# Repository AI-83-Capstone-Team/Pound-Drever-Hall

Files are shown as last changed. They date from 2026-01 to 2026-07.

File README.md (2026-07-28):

# Pound-Drever-Hall Laser Locking System

A hardware/software co-design implementation of a **[Pound-Drever-Hall](https://en.wikipedia.org/wiki/Pound%E2%80%93Drever%E2%80%93Hall_technique) (PDH) laser frequency locking system** on a Red Pitaya STEMlab 125-14 (Xilinx Zynq XC7Z010 SoC). Real-time signal processing runs on the FPGA (PL), a TCP control server runs on the ARM cores (PS), and a Python client API provides remote operation from a host machine. This document covers the basics of the system and its operation.

---

## Table of Contents

0.  [Repository Structure](#repository-structure)
1.  [Why Would You Want This?](#why-would-you-want-this?)
2.  [PDH Conceptual Overview](#pdh-conceptual-overview)
3.  [System Overview](#system-overview)
4.  [Protocol Timing](#protocol-timing)
5.  [PID Controller](#pid-controller)
6.  [FIR Filter](#fir-filter)
7.  [Build and Deploy](#build-and-deploy)
8.  [Hardware Specifics](#hardware-specifics)

---

## Repository Structure

```
core/
  hw/
    prj/pdh_core/
      rtl/               FPGA RTL (SystemVerilog)
        pdh_top.sv       Board-level wrapper: clocking, PS instantiation, HP0 AXI tie-offs
        pdh_core.sv      Main control module: command decoder, IQ rotation, IQ demod, DMA orchestrator
        nco.sv           Numerically controlled oscillator (dual-output, quarter-ROM)
        iq_demod.sv      Instantaneous-product demodulator (configurable ref × input, Q15)
        pid_core.sv      Discrete PID with EMA derivative, anti-windup, decimation
        bram_controller.sv  Dual-clock BRAM capture buffer (pdh_clk write / fclk0 read)
        dma_controller.sv   AXI4 master for HP0 DDR burst writes
        sine_qtr_rom.sv  4096-entry, 16-bit quarter-sine ROM
        posedge_detector.sv  Rising-edge detector utility
      tb/                Testbenches (SystemVerilog, Icarus)
  sim/                   All RTL simulations (cocotb)
    run_regression.py      Runner for the command-echo regression test
    run_bode.py            Open-loop Bode analysis simulation
    run_fir_freq.py        FIR frequency-response verification simulation
    utils/
      test_pdh_core.py     cocotb test module — command-echo checks for every RTL register
      test_bode.py         cocotb test module — open-loop Bode measurement
      test_fir_freq_response.py  cocotb test module — FIR frequency response vs ideal
    Makefile.cocotb        cocotb regression make rules
    Makefile.bode          Bode sim make rules
    Makefile.fir_freq      FIR freq-response make rules
    artifacts/             Auto-indexed simulation output (JSON, CSV, PNG)
  sw/
    server.c            
    control/
      control.c          Command handler implementations
      hw_common.c        Hardware abstraction: mmap of AXI GP0 and HP0 DMA region; UIO interrupt primitives
      inc/
        server.h         cmd_ctx_t, cmd_entry_t, output_item_t definitions
        hw_common.h      pdh_cmd_t, pdh_callback_t, dma_frame_t packed unions; all enums
        control.h        Command handler declarations
  dts/
    pdh_irq.dts          Device Tree overlay — binds /dev/uio/pdh_uio to IRQ_F2P[1] (GIC SPI 62)
client/
  gui.py                 Interactive tkinter GUI — full hardware control without scripting
  pdh_api/
    api.py               Python API functions wrapping each TCP command
    types.py             Enums and result dataclasses mirroring the C/RTL types
    fir_design.py        Windowed-sinc FIR lowpass design (shared by GUI and sim tooling)
  test.py                Board-level regression test and visualization script
sim/
  pdh.m                  MATLAB PDH signal simulation
  power_terms.m          MATLAB power series analysis
pcb/                     PCB design files
```

---

## Why Would You Want This?

An ideal laser is a light source where the emitted field is perfectly coherent. In other words, if you sample the field at any two points in space or any two points in time, there's a deterministic phase relationship between them. This doesn't actually happen in practice. Various noise sources can introduce photons that are out of phase with the main field, and once those mix in, the aggregate phase of the beam starts doing something partially random. At that point the deterministic relationship breaks down and the beam is no longer coherent. This is a problem when the exact phase or frequency of the laser needs to be maintained. One example is gravitational wave detection, where the phase difference between two laser beams encodes spatial distortion from a passing wave. Another is optical communication using Phase-Shift Keying (PSK), where information is encoded in the relative phase of the carrier. And since frequency is just the first derivative of phase and wavelength follows from frequency, random phase noise also translates to wavelength jitter — which matters in applications like laser isotope separation, where the wavelength needs to sit on the absorption line of a specific isotope. There are a bunch of other examples but they won't be covered here.

| Good Laser | Bad Laser |
|:---:|:---:|
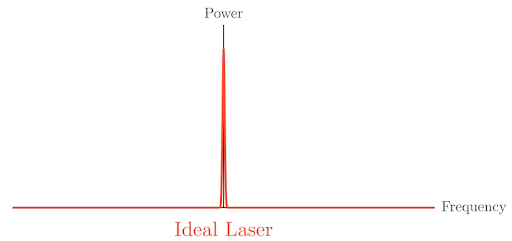
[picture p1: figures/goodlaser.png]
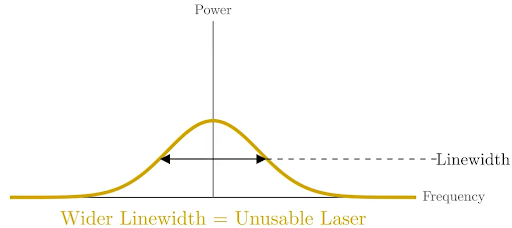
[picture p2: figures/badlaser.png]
|  |  |

#### TLDR; Really clean lasers can be useful.

---

## PDH Conceptual Overview

The main thing we can take advantage of is that if we keep the wavelength fixed, then by extension we can keep the phase fixed. We also know that we can adjust the wavelength by adjusting the amount of power we supply to the laser. We do this by using a frequency discriminator, which is a special optical component (generally either a Fabry Perot Cavity or a Ring Resonator) that emits a signal whenever the wavelength of the beam deviates from the resonance point. This is not good enough though because it doesn't tell us whether the wavelength is too wide or too narrow. To handle this, we use an Electro-Optic Modulator (EOM) to apply a periodic phase shift to the input beam. We then take the output beam and pass it to a photodiode to convert it to an electrical signal before multiplying it by the same sinusoidal signal driving our EOM. At this point, the multiplication product will reflect both the magnitude AND direction of our deviation from the resonance wavelength:

| Time Domain Representation | Frequency Domain Representation |
|:---:|:---:|
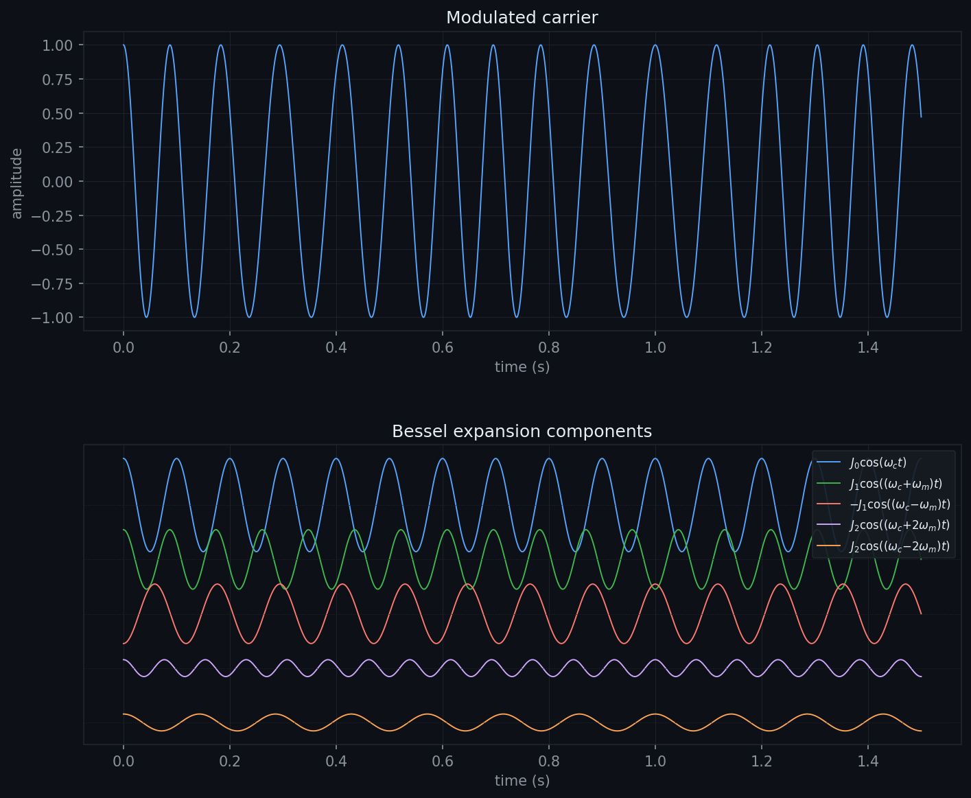
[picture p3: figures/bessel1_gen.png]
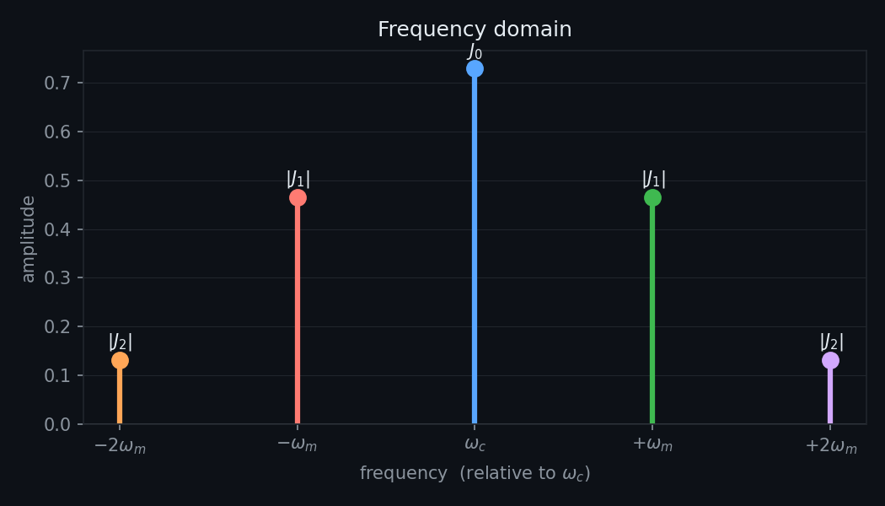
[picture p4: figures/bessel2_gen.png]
|  |  |

Above are time-domain and frequency domain representations of our modulated signal, which we can break into a series of superimposing sinusoids. The red and green tones are our sidebands, and we use them to encode the frequency offset information.

#### TLDR; Beam->EOM->Cavity->Photodiode->Demodulator
#### Alternative TLDR; We use the sidebands to encode our error signal, then demodulate them to extract it. From there we can generate a control signal to correct our laser.

---
## System Overview

The general idea behind the system is anything that needs to be done fast and/or deterministically and/or interact with the physical world is done on the FPGA, anything that doesnt but still needs to interact with the FPGA is done on the hard processor (ARM Cortex A9), and everything else is done client-side. The system is similar to [Linien](https://github.com/linien-org/linien), albeit much less polished and much more hackable. Hackability in this context refers to giving the user direct control over as much of the RTL as possible — you can basically wire the inputs and outputs of any two modules inside the system up to each other in any way that you wish, which makes rapid ad-hoc lab tests on the fly easy. As such, the system is not only useful as a laser spectroscopy lock, but also as a lightweight oscilloscope, spectrum analyzer, PID controller, FIR filter, and function generator all in one. 

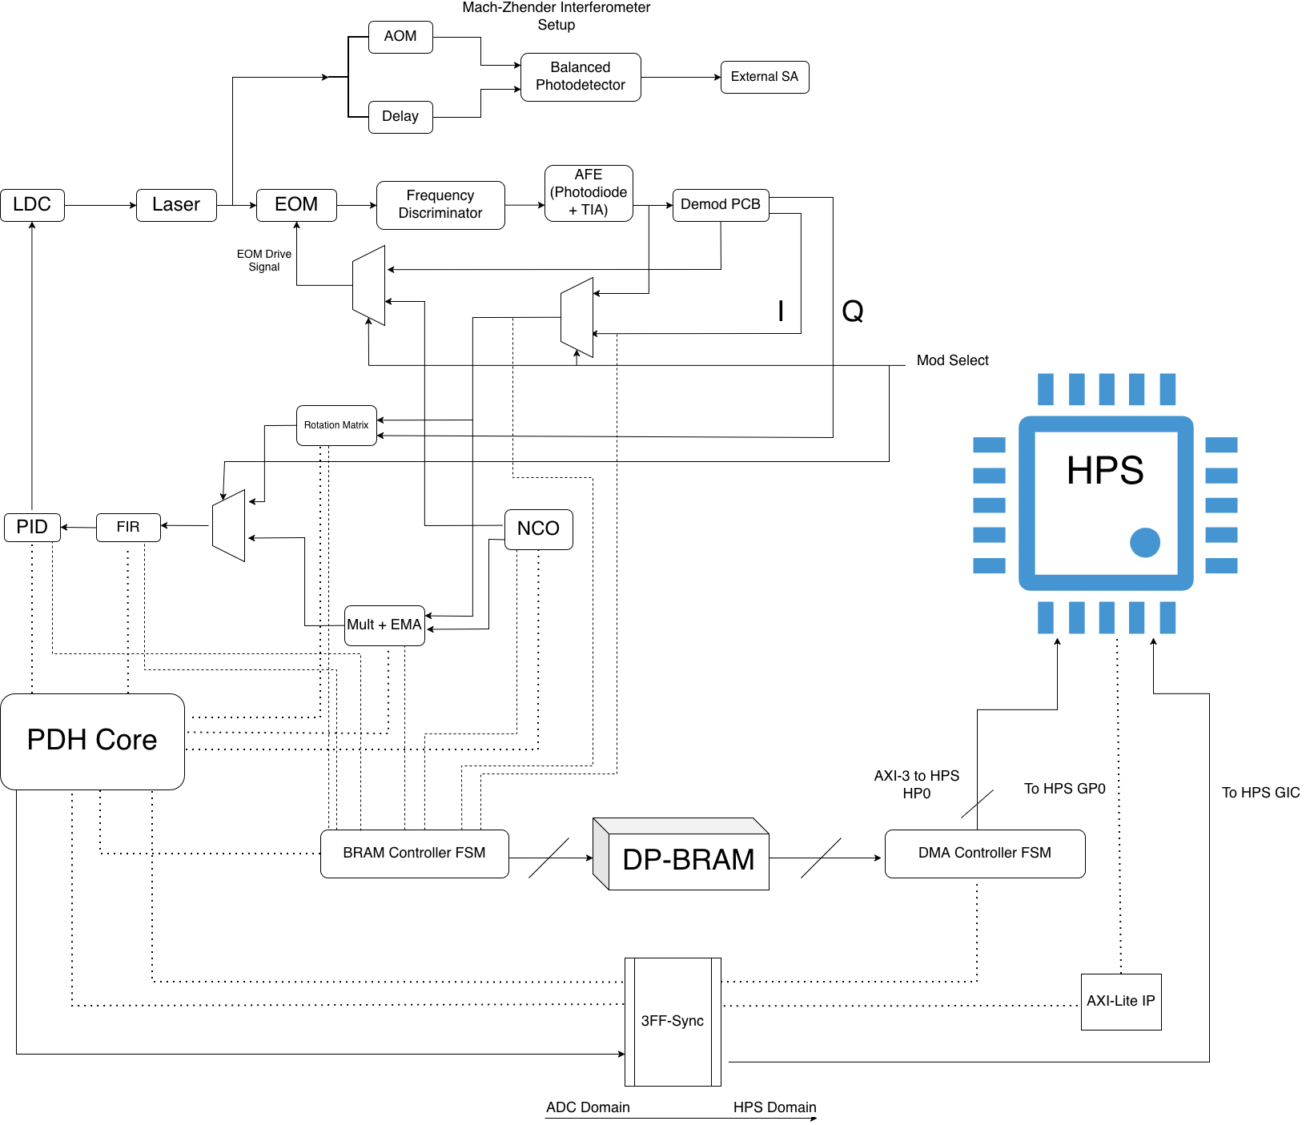
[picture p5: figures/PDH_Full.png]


In the diagram above, dotted lines indicate control/callback signals routed to/from submodules by the PDH core. Dashed lines indicate data taps that can be selected to feed the DMA engine. 

TLDR; it's a baby Moku.

---
## Protocol Timing

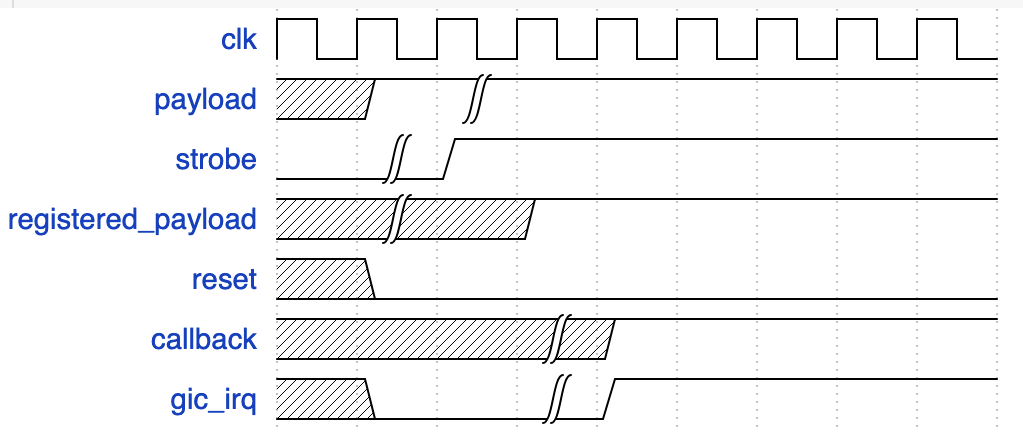
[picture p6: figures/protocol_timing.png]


The command word is 32 bits: [31]=reset, [30]=strobe, [29:26]=command code, [25:0]=payload. Every transaction consists of the PS writing the word twice, first with strobe low and then with strobe high. The FPGA passes the raw GPIO input through a 3-stage flip-flop synchronizer before decoding it, which handles the clock domain crossing between the PS AXI bus and the 125 MHz fabric clock. A posedge detector on the synchronized strobe fires when that edge comes through, latching the command word and executing it on that same clock cycle. The callback register is combinatorial off the current state, so it's valid at that same point. A 1-cycle GIC interrupt fires coincident with the strobe edge detection. The C server is blocked on a `read()` of `/dev/uio/pdh_uio`, which unblocks when the interrupt fires, and the callback register gets sampled.

`CMD_GET_FRAME` is different. No interrupt fires on the strobe. The DMA state machine runs through its sequence (BRAM fill at the decimated rate, then an AXI4 burst to DDR over HP0), and the interrupt fires when the transfer is done. The server side waits on `select()` with a timeout computed from the decimation depth rather than blocking indefinitely.

`CMD_IDLE` generates no interrupt at all. It just resets the DMA state machine back to armed so the next `CMD_GET_FRAME` starts clean.

The reset bit is completely separate from the strobe path and goes straight to the synchronous reset chain regardless of anything else in the word.

#### TLDR; PS writes command word twice (strobe 0→1), FPGA latches on the synchronized rising edge, callback is valid on that same clock cycle, interrupt tells the PS it's ready.

---
## PID Controller

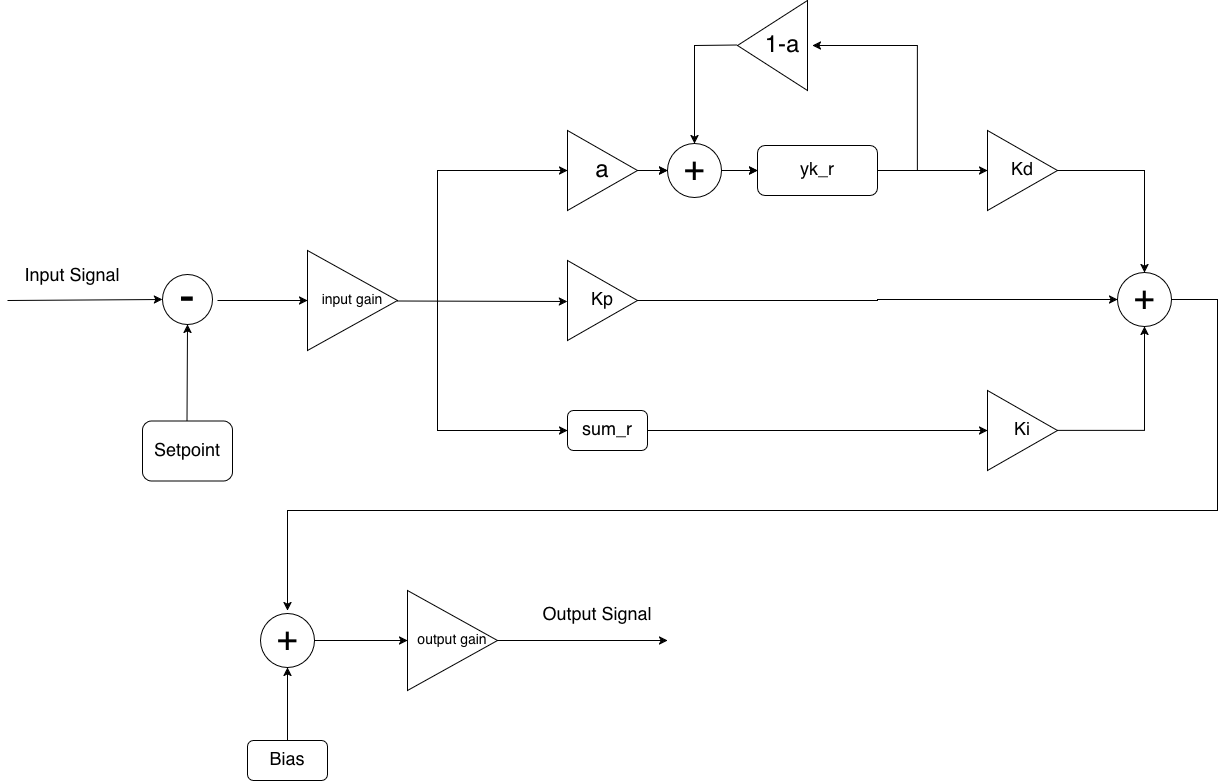
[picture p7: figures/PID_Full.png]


The block diagram shows the structure. The input signal has the setpoint subtracted, passes through the input gain stage (`egain`), and then splits into three paths: Kp directly, Kd via the EMA block, and Ki through the running integrator (`sum_r`). The three products are summed and then scaled by the output gain before the bias is added.

The derivative path is worth explaining since it's not a standard differentiator. The core keeps a running exponential moving average of the error (`yk_r` in the diagram). The alpha and (1-alpha) scaling blocks feed into that register's update loop, and Kd multiplies the difference between the current error and `yk_r`. That difference is the deviation of the error from its recent mean, which is a reasonable approximation of the derivative without being as noise-sensitive as a true differentiator. The alpha parameter sets the EMA time constant.

The integrator has saturation at ±2^`satwidth` and freezes in whichever direction would push it further when the output is already railed. Standard anti-windup. Without it the integrator winds up to full scale any time the system is outside the lock pull-in range and then takes forever to recover once it gets back in.

The output is 14-bit unsigned offset-binary (DAC code), with 0 V mapped to code 8191. The decimation parameter slows the PID update rate independently of everything else — the NCO, ADC, and DMA all still run at full rate, the PID output just holds between updates.

#### TLDR; Standard PID with EMA derivative and integrator anti-windup. Kp/Ki/Kd are Q15 fractions, input and output gain stages let you scale without touching the individual terms.

---
## FIR Filter

| Original Signal | Sampling at Decimated Rate |
|:---:|:---:|
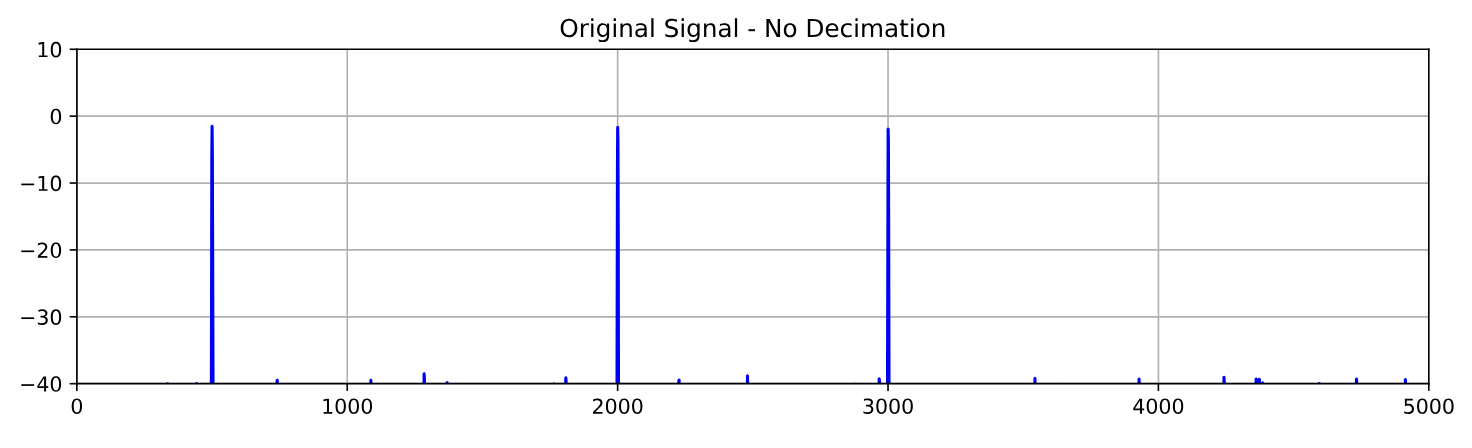
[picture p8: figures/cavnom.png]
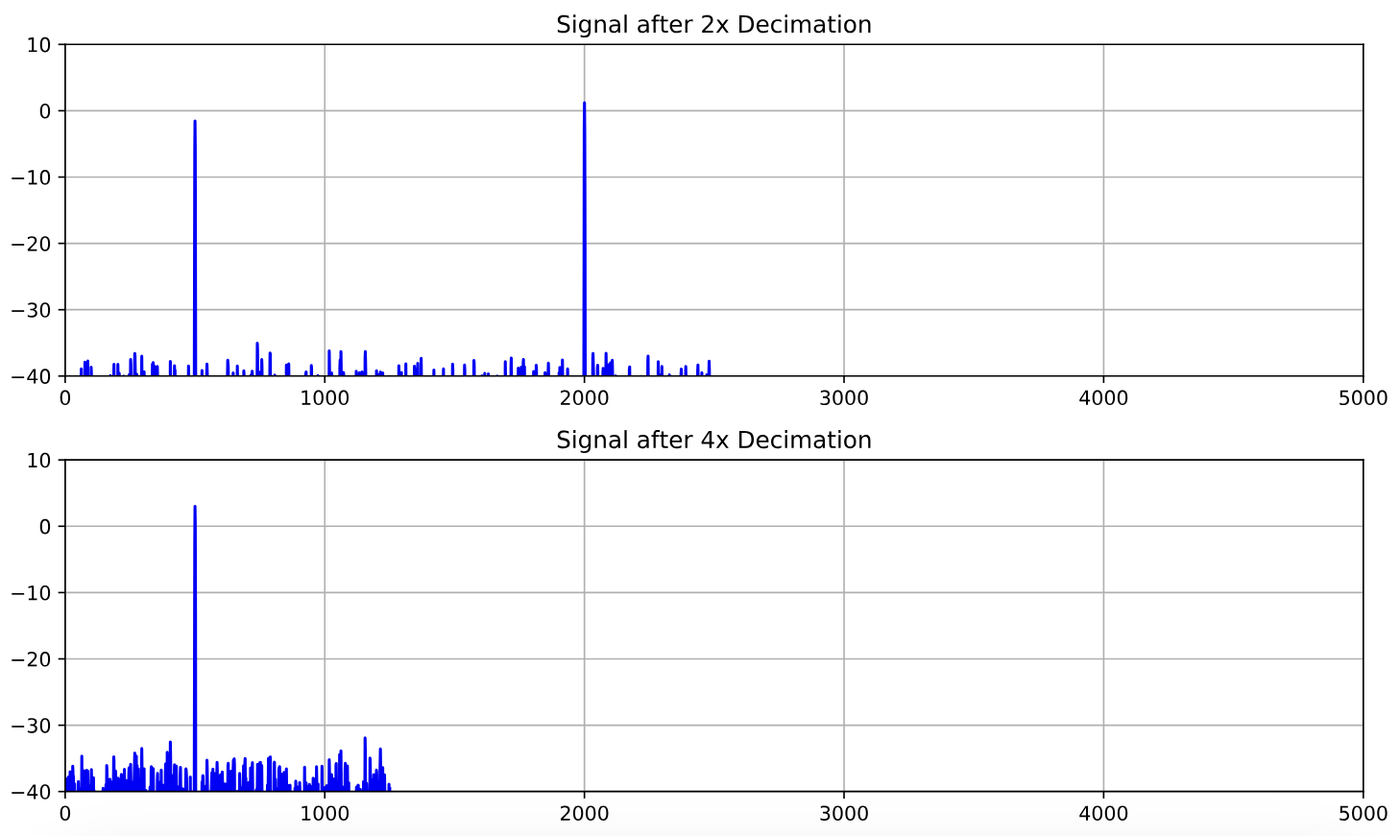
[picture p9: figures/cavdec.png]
|  |  |

The FIR is there to anti-alias before the PID's decimation stage. The structure is a 32-tap direct-form filter with a registered saturating adder tree reducing all the tap outputs down to one. The diagram below shows it: the input clocks through a shift register along the top, each stage multiplies by its stored coefficient, the products register, and get summed pairwise down to the output. Saturation is applied at every add level so overflow can't propagate up the tree. 32 taps means 5 levels of pairwise adds plus the one tap-level register, so 6 cycles of total pipeline latency.

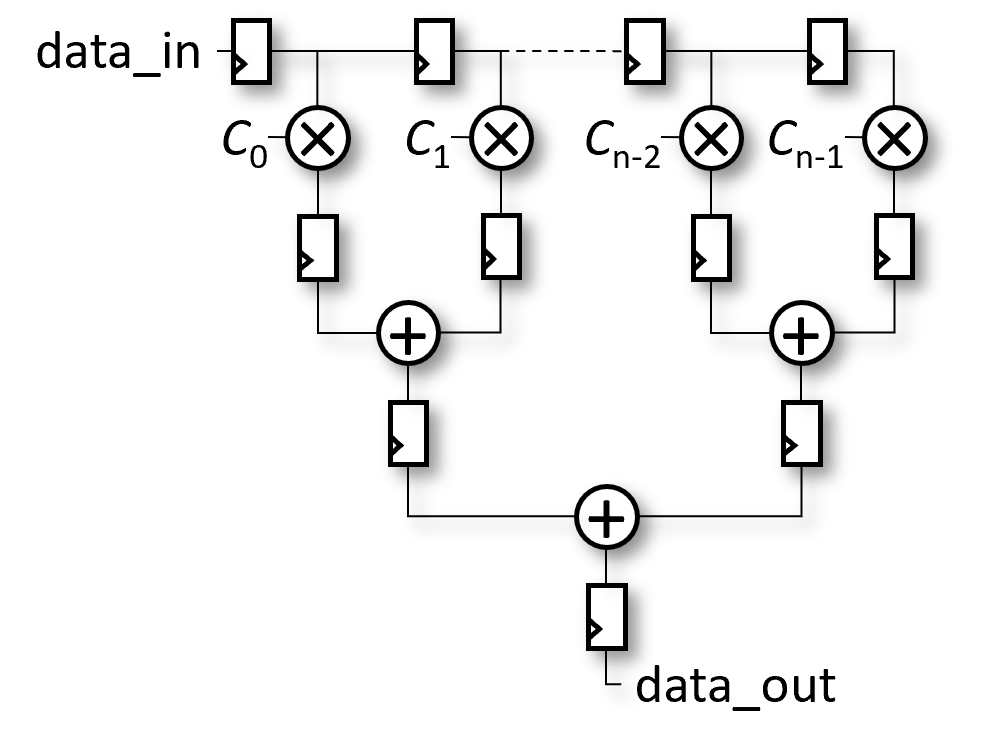
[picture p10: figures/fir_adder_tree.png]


The coefficients are a windowed sinc, the ideal lowpass impulse response truncated to 32 samples and multiplied by a window. The diagram below shows how that maps onto the input samples.

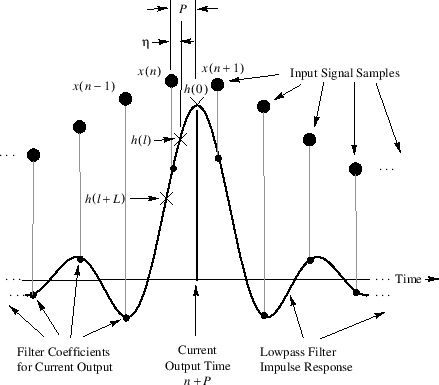
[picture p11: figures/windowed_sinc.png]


Coefficients are loaded by writing them one at a time into a staging memory, then atomically committing the whole set to the active tap registers in one shot. This means the filter never runs with a partially-updated coefficient set during a live load.

| FIR Ideal vs RTL Freq Resp | H(w) Comparison With Different Windowing Schemes|
|:---:|:---:|
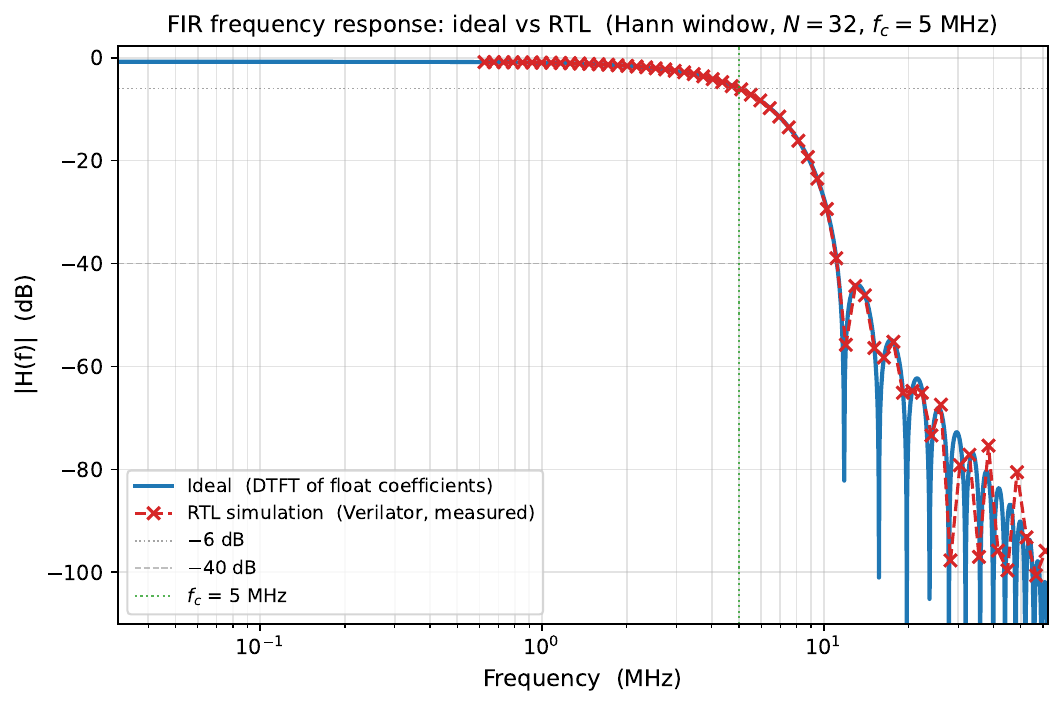
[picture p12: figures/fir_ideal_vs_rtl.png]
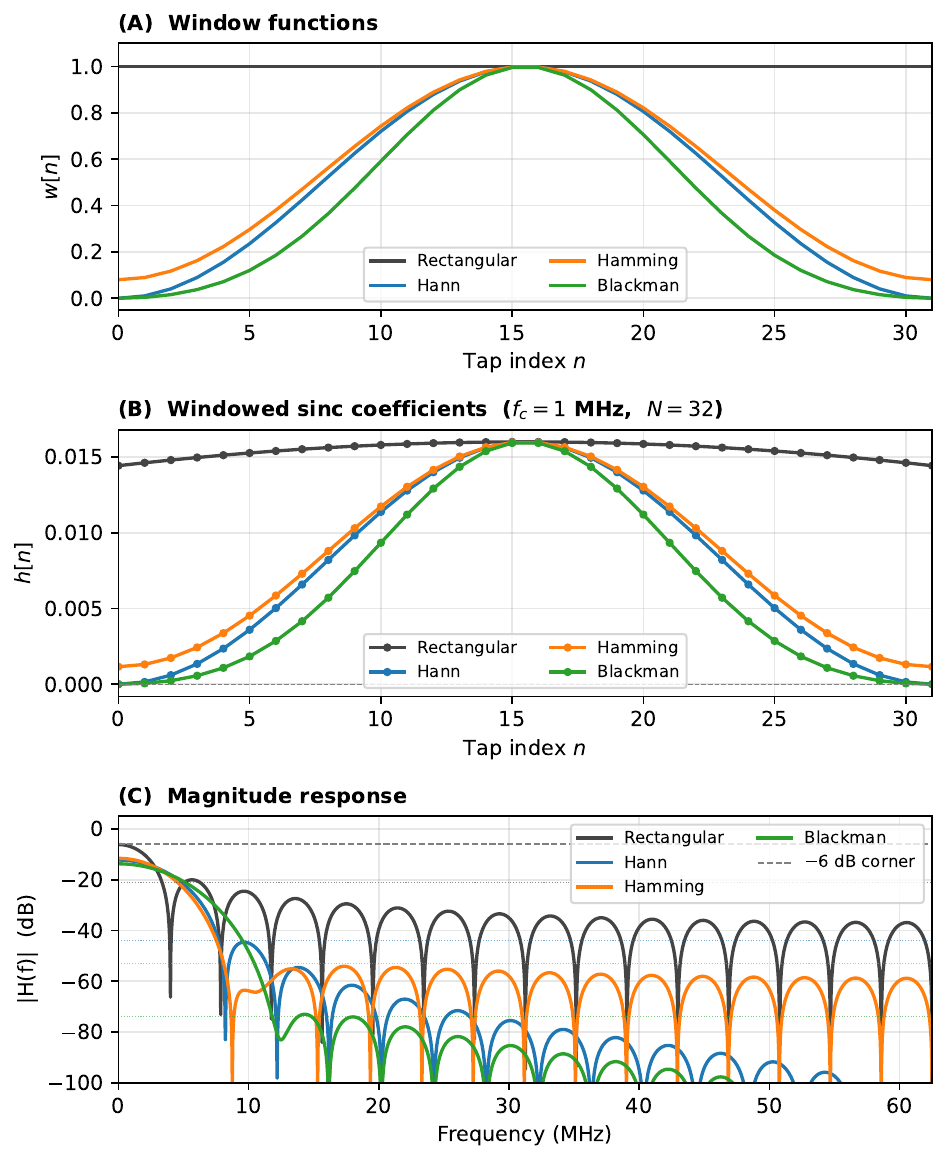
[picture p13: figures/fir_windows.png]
|  |  |

The frequency response plot on the left is for a Hann-windowed design at fc=5 MHz with N=32. The RTL simulation tracks the ideal floating-point response closely down to about -80 dB, which is roughly where Q15 quantization noise lifts the stopband floor. The right figure shows the tradeoff between windowing schemes. Rectangular has the sharpest transition band but terrible sidelobe rejection. Blackman gets to -75 dB or better at the cost of a wider transition. For a PDH lock where the EOM modulation frequency is well separated from the cavity linewidth, Blackman or Hann is the right call.

The capture below is from hardware. fir_in is the raw wideband signal going into the filter, fir_out is the 100 kHz lowpass output.

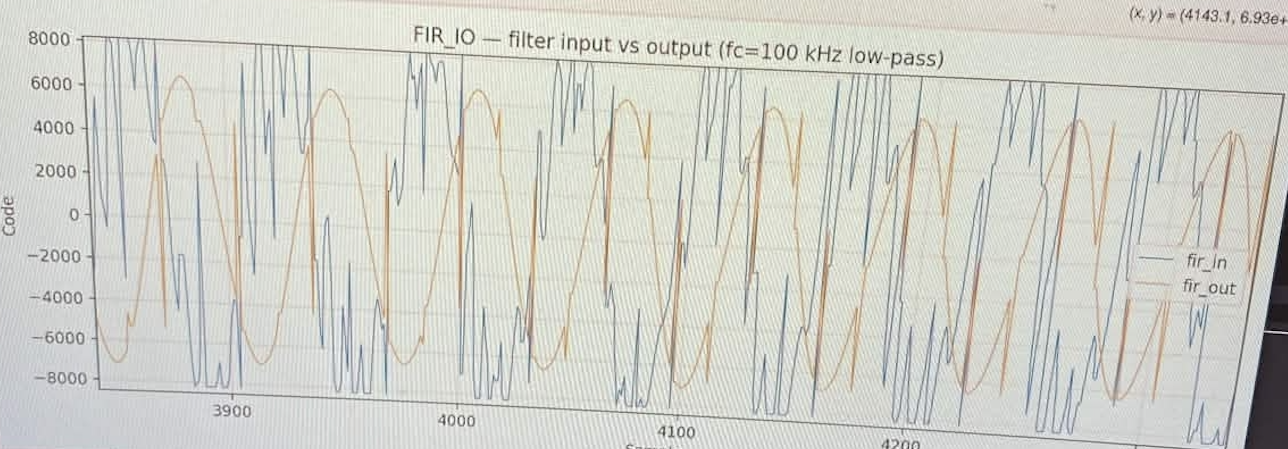
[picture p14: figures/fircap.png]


## Build and Deploy

Please note that the specific IP adress below is just a placeholder. To determine the IP for your system, locate the Red Pitaya MAC adress via sticker and find the IP mapping to that MAC. On Linux and Mac you can do this via `arp -a <your_mac_address_here>`

### RTL (FPGA Bitstream)

```bash
cd core/hw
make pdh_core       # Runs Vivado in batch mode; output: build/boot.bin
make clean
```

Requires Vivado and `bootgen` in PATH.

### Software (C Server)

```bash
cd core/sw
make server         # Cross-compiles for ARM; statically linked (-static -lm -lstdc++ -lpthread)
make clean
```

### Deploy (manual — raw SSH/SCP)

`deploy.sh` is not used. All deployment is done with plain `ssh`/`scp`.  Target: `root@10.42.0.62` (password: `root`).

#### 1. Flash the bitstream

```bash
# Copy bitstream to RP
scp core/hw/build/boot.bin root@10.42.0.62:/root/boot.bin

# Program the FPGA (full path required — fpgautil may not be in PATH over SSH)
ssh root@10.42.0.62 '/boot/bin/fpgautil -b /root/boot.bin -o /lib/firmware/base.dtbo'
```

#### 2. Build and copy the server

```bash
cd core/sw && make server
# Remove old build, copy fresh one
ssh root@10.42.0.62 'rm -rf /root/sw'
scp -r core/sw root@10.42.0.62:/root/sw
```

#### 3. Load the DTS overlay (PL-to-PS interrupt)

The interrupt path requires a Device Tree overlay that binds `/dev/uio/pdh_uio` to GIC SPI 62 (`IRQ_F2P[1]`).

```bash
# Compile the overlay on the host
dtc -I dts -O dtb -o core/dts/pdh_irq.dtbo core/dts/pdh_irq.dts

# Copy to RP
scp core/dts/pdh_irq.dtbo root@10.42.0.62:/root/pdh_irq.dtbo

# On the RP: remove any stale overlay, then load the new one
ssh root@10.42.0.62 '
    rmdir /sys/kernel/config/device-tree/overlays/pdh_irq 2>/dev/null || true
    mkdir -p /sys/kernel/config/device-tree/overlays/pdh_irq
    cp /root/pdh_irq.dtbo /sys/kernel/config/device-tree/overlays/pdh_irq/dtbo
'
```

After loading, verify the UIO device appears:

```bash
ssh root@10.42.0.62 'ls /dev/uio/pdh_uio'
```

#### 4. Start the server

**The server must be started from `sw/build/`** — `cmd_get_frame` writes `dma_log.csv` relative to the working directory.

```bash
ssh root@10.42.0.62 'cd /root/sw/build && ./server &'
```

#### 5. Start the GUI from your client
```Python
python gui.py
```

At this point, you should see something similar to the below:

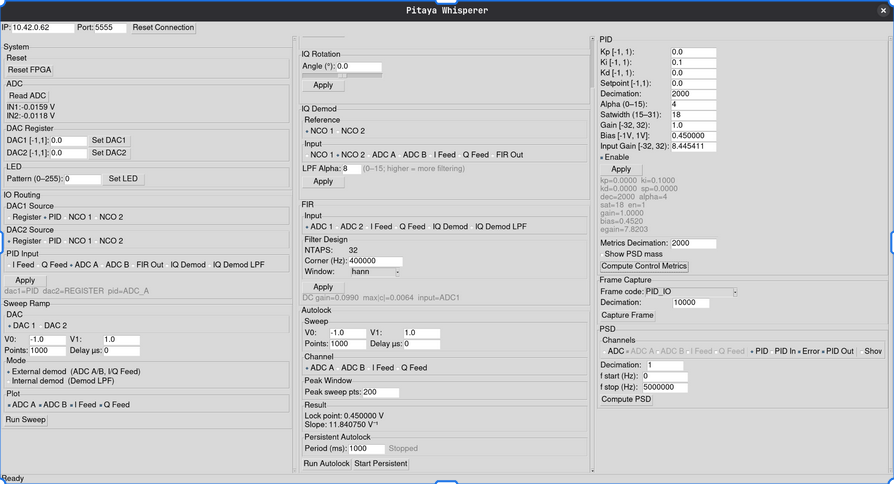
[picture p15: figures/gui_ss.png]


## Hardware Specifics

The system is currently meant to be run on a [STEMLab 125-14](https://redpitaya.com/stemlab-125-14/?srsltid=AfmBOopgVo9Tuy0RZu55bZxuKTTzMArpQeF5WWGbn-Z-MORJmZ4-cLcS) (both generations should work but it has been tested on Gen1). If porting to another system, ensure that the ADC and DAC coding schemes are adjusted accordingly. 

The AD9767 only has one input port connected on the r125-14. Therefore the system configures it to run in interleaved mode coherent with the timing diagram below.

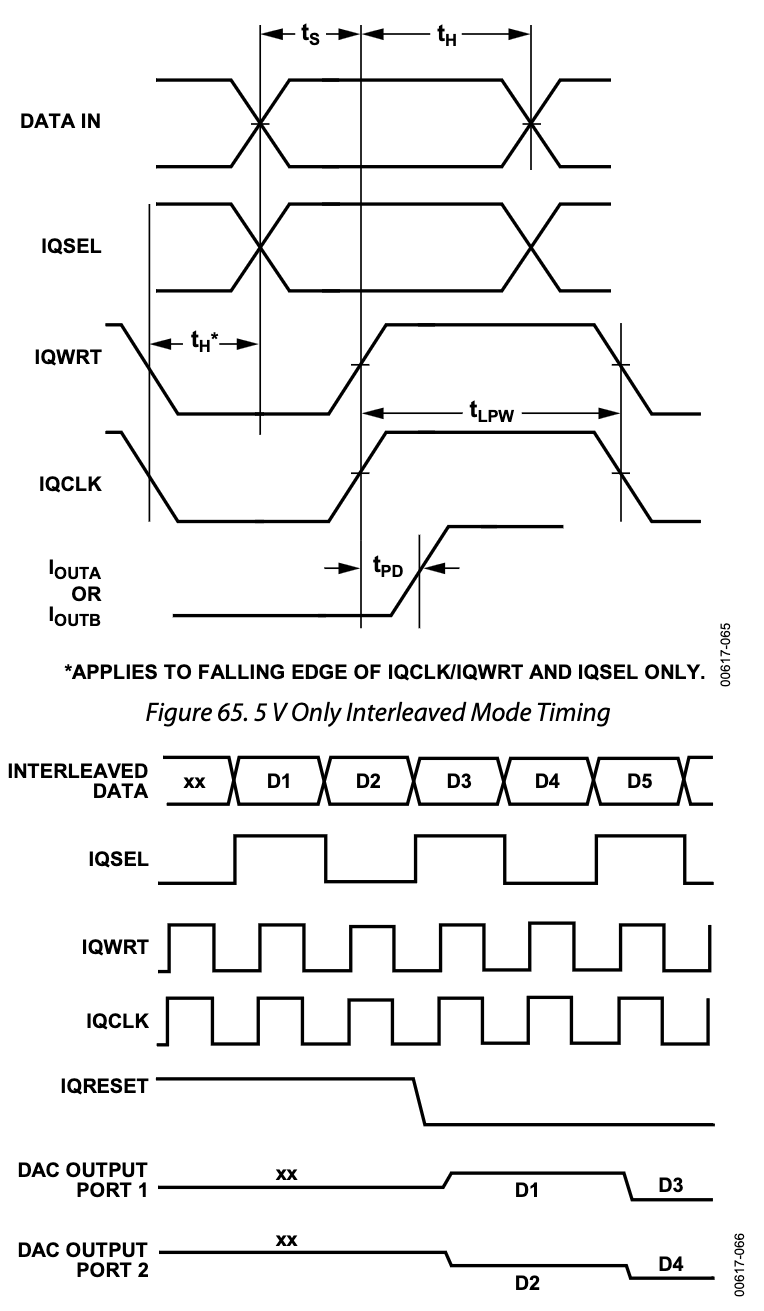
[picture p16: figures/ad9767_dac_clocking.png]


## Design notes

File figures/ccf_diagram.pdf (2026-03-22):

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

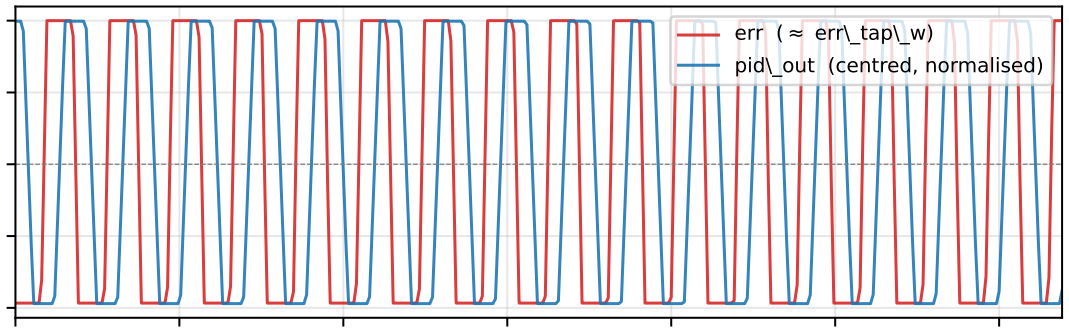
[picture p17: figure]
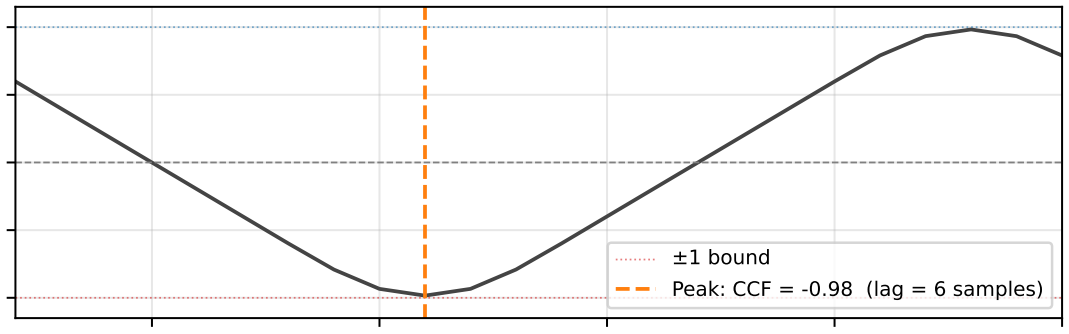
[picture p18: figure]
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

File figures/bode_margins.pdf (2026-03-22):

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

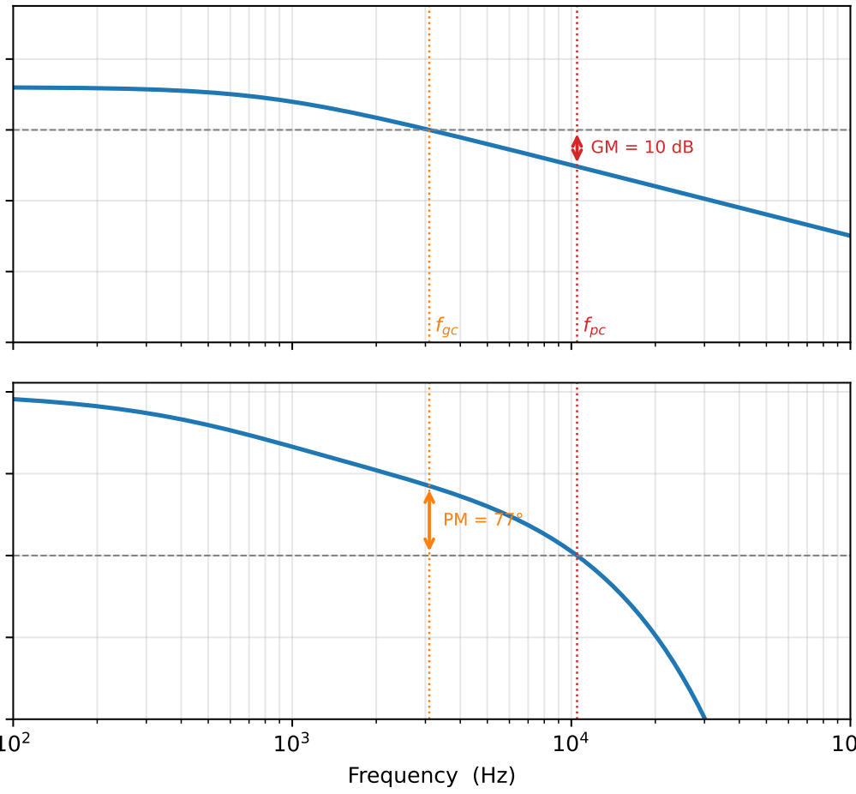
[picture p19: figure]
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

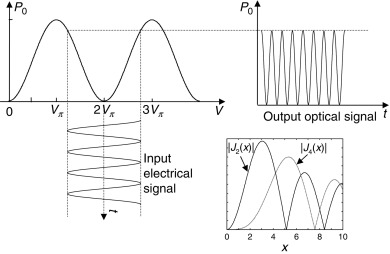
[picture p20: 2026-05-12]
figures/eom.jpg

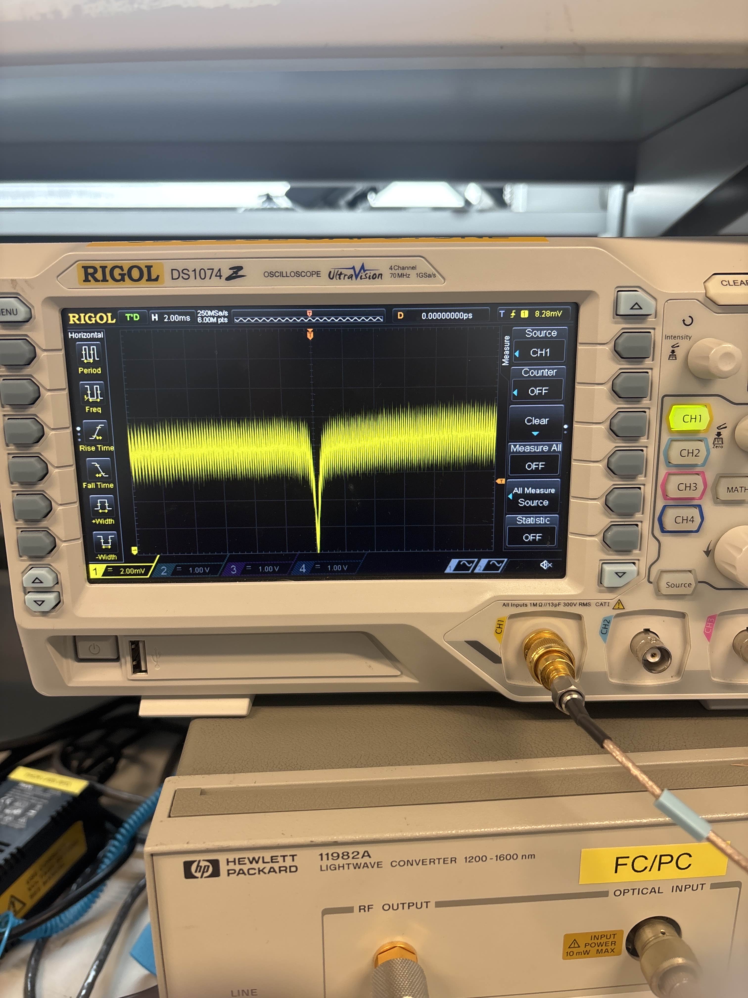
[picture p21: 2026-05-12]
figures/cavity1.jpg

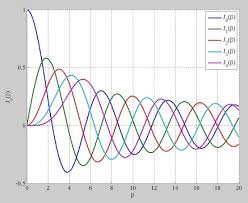
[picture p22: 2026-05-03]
figures/bessel1.jpg

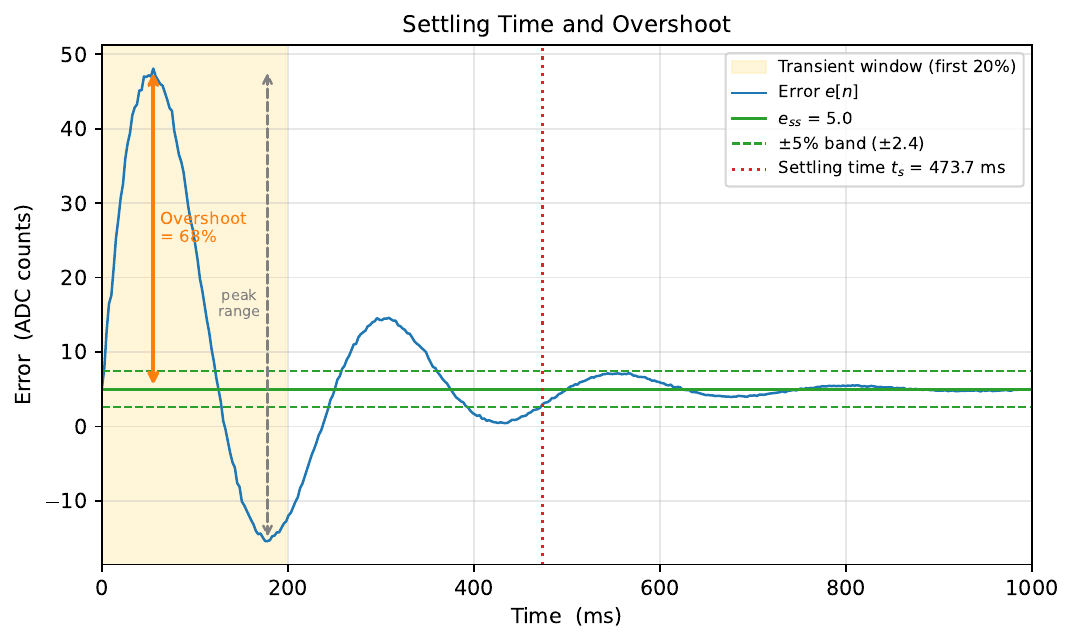
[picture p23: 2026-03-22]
figures/settling_overshoot.png

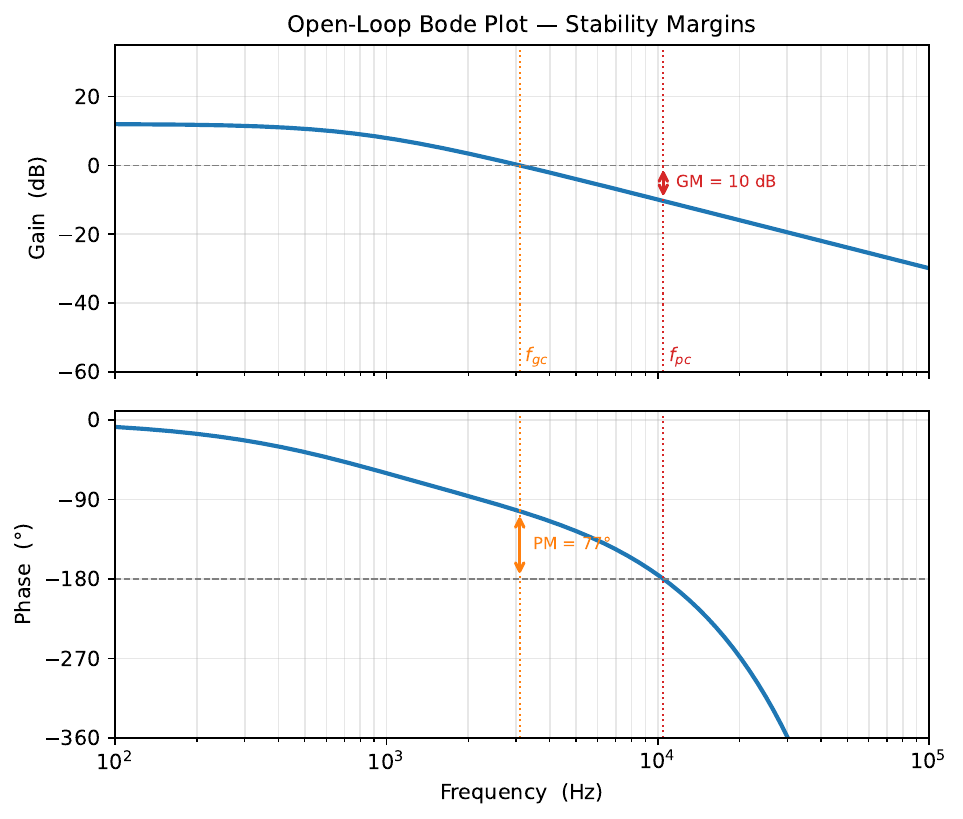
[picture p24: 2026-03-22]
figures/bode_margins.png

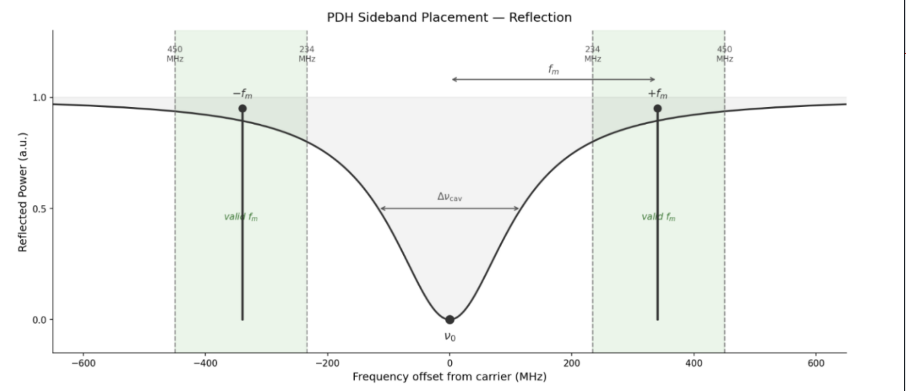
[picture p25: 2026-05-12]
figures/cavlw_cap.png

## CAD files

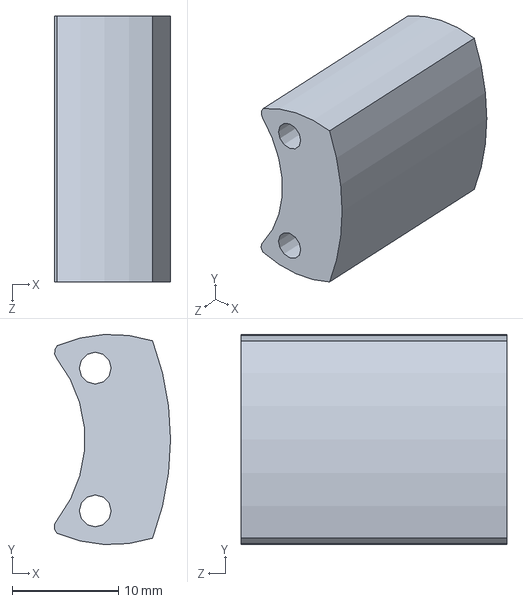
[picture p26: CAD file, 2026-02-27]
pcb/tia/cad/pd_socket_rework/Spacer_25mm.SLDPRT
10.9 x 19.7 x 25.0 mm

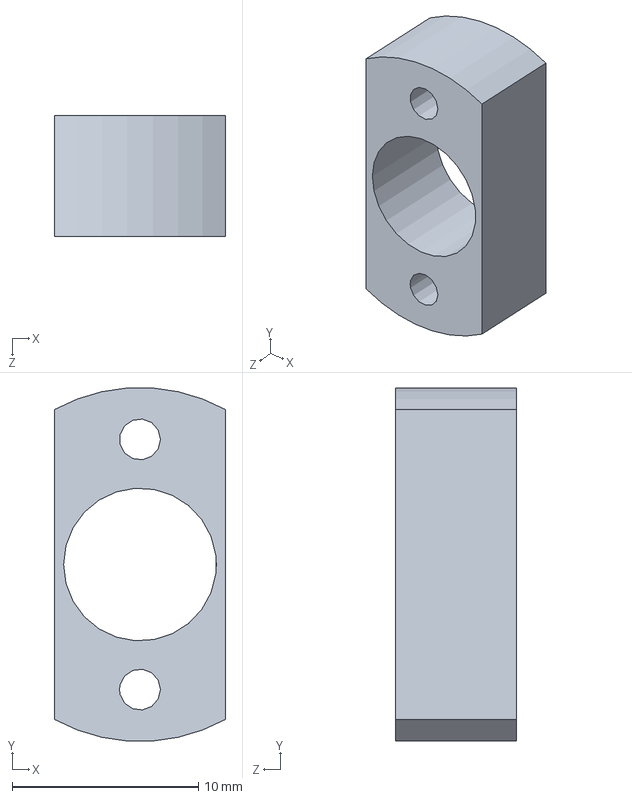
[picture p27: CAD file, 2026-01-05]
pcb/tia/cad/pd_spacer/Spacer_6.5mm.sldprt
9.20 x 19.0 x 6.50 mm

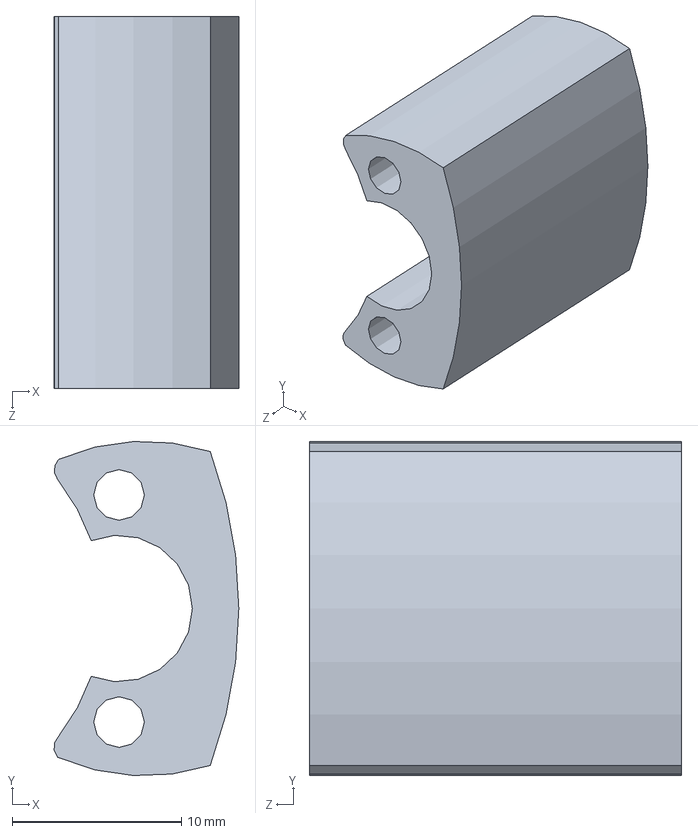
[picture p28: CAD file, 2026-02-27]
pcb/tia/cad/pd_socket_rework/Spacer_22mm.SLDPRT
10.9 x 19.7 x 22.0 mm

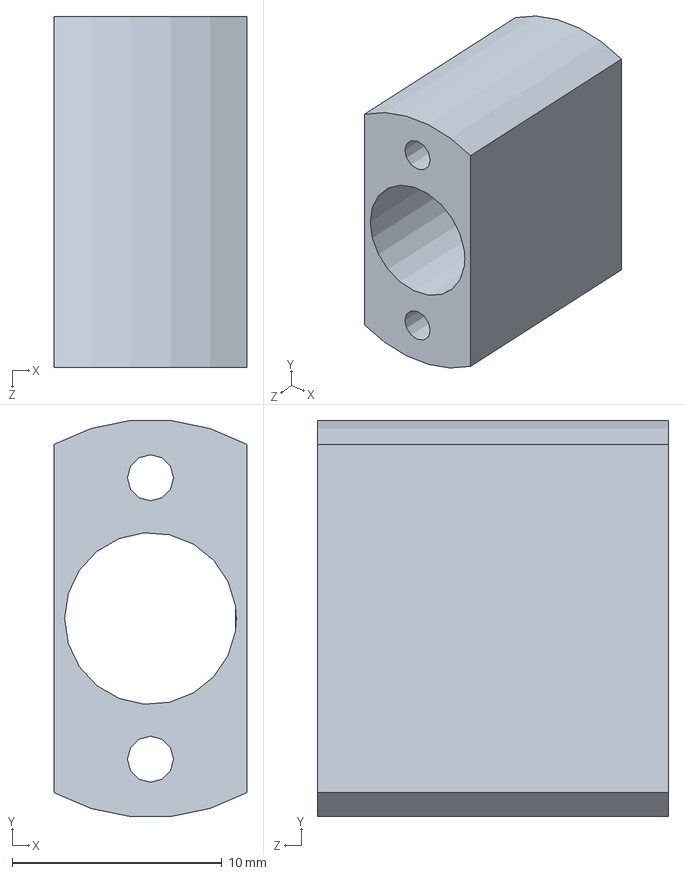
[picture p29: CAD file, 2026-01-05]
pcb/tia/cad/pd_spacer/Spacer_16.75mm.sldprt
9.20 x 18.9 x 16.8 mm

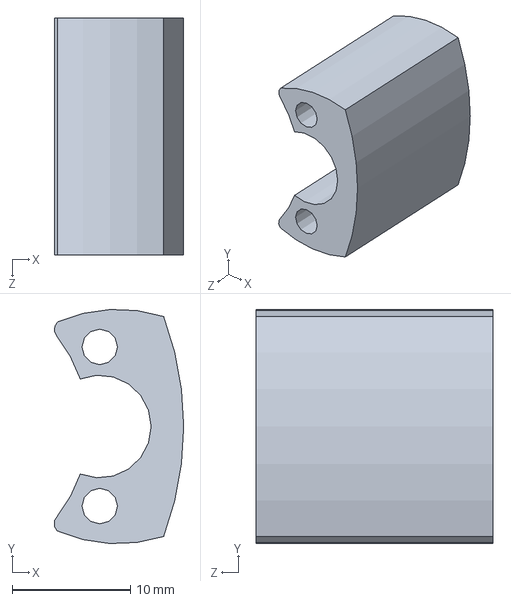
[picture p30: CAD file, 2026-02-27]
pcb/tia/cad/pd_socket_rework/Spacer_20mm.sldprt
10.9 x 19.7 x 20.0 mm

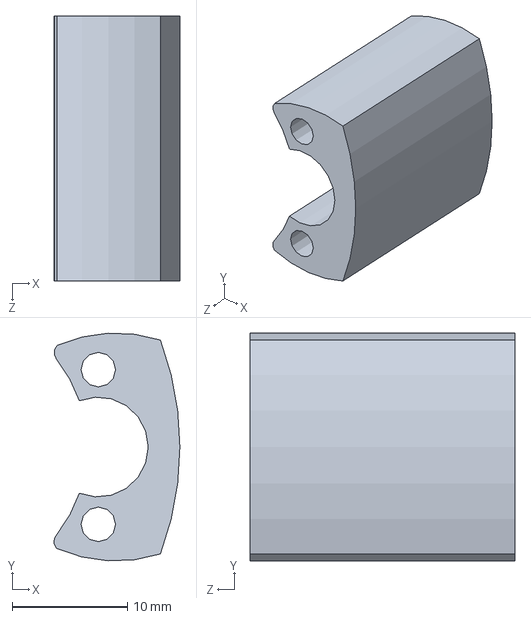
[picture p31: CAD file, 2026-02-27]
pcb/tia/cad/pd_socket_rework/Spacer_23mm.SLDPRT
10.9 x 19.7 x 23.0 mm

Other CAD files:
pcb/tia/cad/pd_socket_rework/Spacer_20mm.STL
pcb/tia/cad/pd_socket_rework/Spacer_22mm.STL
pcb/tia/cad/pd_socket_rework/Spacer_23mm.STL
pcb/tia/cad/pd_socket_rework/Spacer_25mm.STL
pcb/tia/cad/pd_spacer/Spacer_16.75mm.STL
pcb/tia/cad/pd_spacer/Spacer_6.5mm.STL

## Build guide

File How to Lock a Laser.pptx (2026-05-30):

## How to Lock a Laser

Nolan McCleary

(With Pictures)

## What is a Laser and Why is it Useful?

- A perfect laser produces light waves that are all in phase with one another
- This coherence can be exploited to do useful things
  - Interferometry, where relative phase differences between two beams encodes spatial distortions
  - Optical PSK, where the relative phase differences encodes a transmission symbol
  - Lithography applications where an extremely precise wavelength and high degree of coherence is required

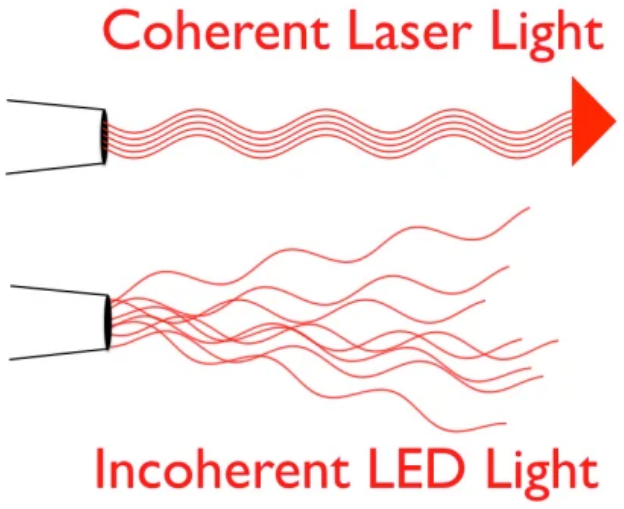
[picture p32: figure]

## The Problem

- Real lasers are not ideal
- Both the laser’s phase and frequency are subject to random fluctuations

Expectation

Reality

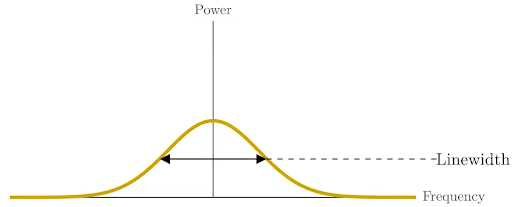
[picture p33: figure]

## The Solution

- We don’t know how much each noise source contributes to our overall frequency noise
- However, we do know that adjusting the current into the laser diode will let us adjust the beam’s wavelength/frequency
- If we can measure frequency deviation at any given point in time, we can adjust the current to cancel it out i.e. we can keep the frequency fixed
- Doing this will let us stabilize both the frequency and the phase of the laser since phase is just the accumulated history of frequency

Big Idea: Control current to control frequency, control frequency to control phase

## How Do We Measure This?

- We can use some sort of frequency discriminator to give us a signal whenever the beam’s wavelength (and thus frequency) deviates from resonance
- One way we can do this is with a ring resonator

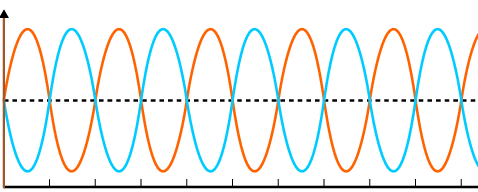
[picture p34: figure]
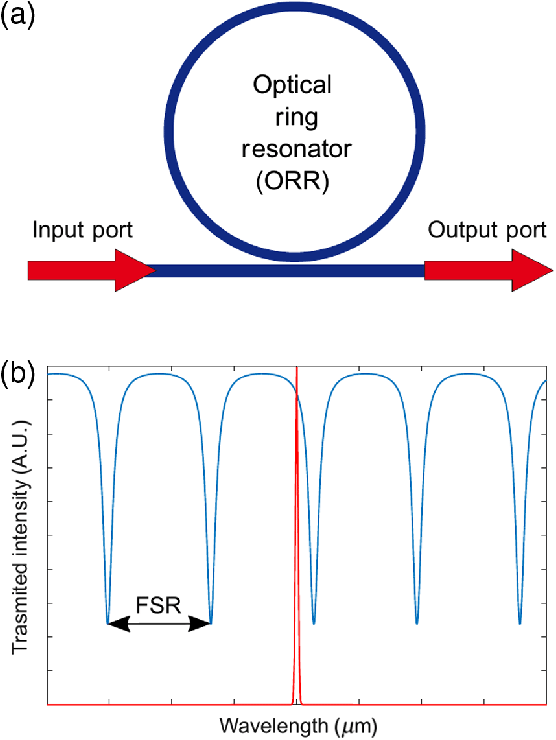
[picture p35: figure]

## Complex Conjugate FD Response

- FD creates a new field and adds it back to the input field
- Resultant field can be modelled as a stretch/rotation of the input field
- Resultant fields from detune in either direction are complex conjugates of one another

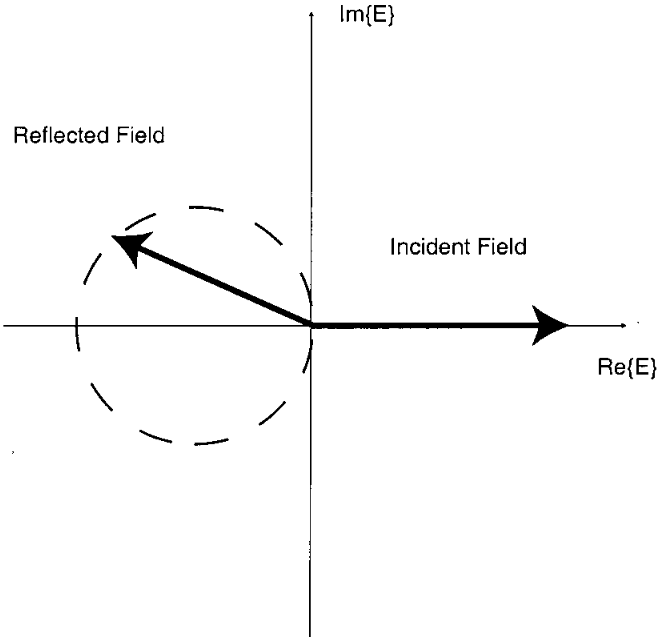
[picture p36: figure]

## Bessel Expansion of a Modulated Sinusoid

- If we modulate the phase of the input field, we can expand it with a Bessel Series
- Cavity response now primarily composed of ~3 main fields when beta < 1
  - Carrier signal and two sidebands
- Imaginary component of sideband response won’t change sign when detune direction reversed, carrier’s will

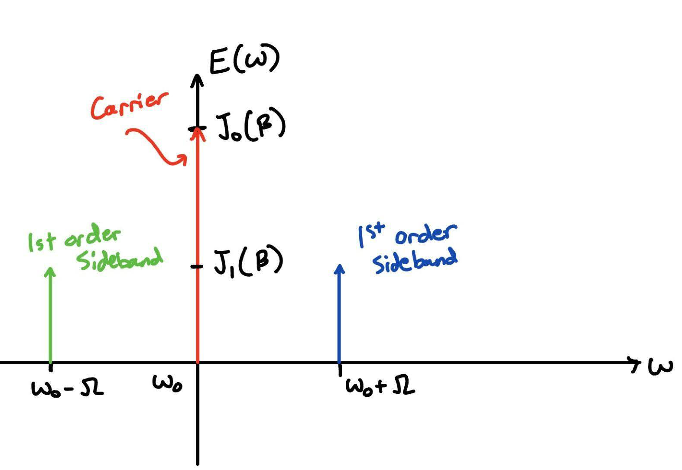
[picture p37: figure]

## Getting Rid Of The Carrier

- Photodiode current is proportional to our optical power, optical power is proportional to the length of our
- Once we have the current, we can convert it to a voltage and feed it to our demod + control

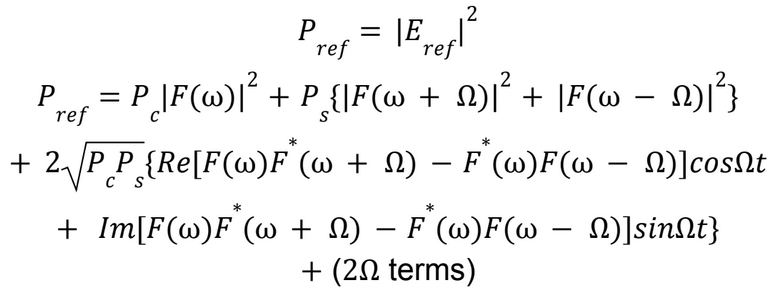
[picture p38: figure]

Complex vector rotating at modulation frequency that flips by 180 degrees when detune direction changes

## After Demodulating

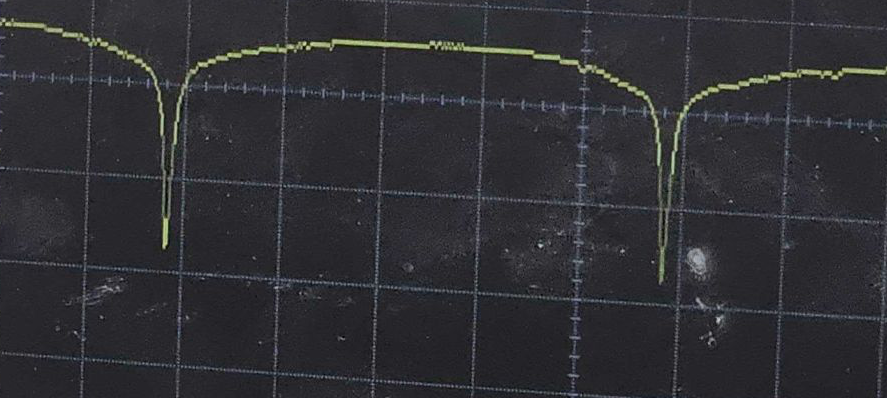
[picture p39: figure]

- Demodulate photodiode output to generate a new signal
- New signal is odd-symmetric about resonance now
- Since we now have magnitude and direction of the detuning, we can use it as an input signal to our controller

Positive detune

Resonance

Negative detune

## Issue: Optical Gain

- How much optical power we expect to recover per unit detune dictates SNR of signal fed to controller
- Some noise we can’t eliminate, but we can make it a proportionately smaller part of our input signal

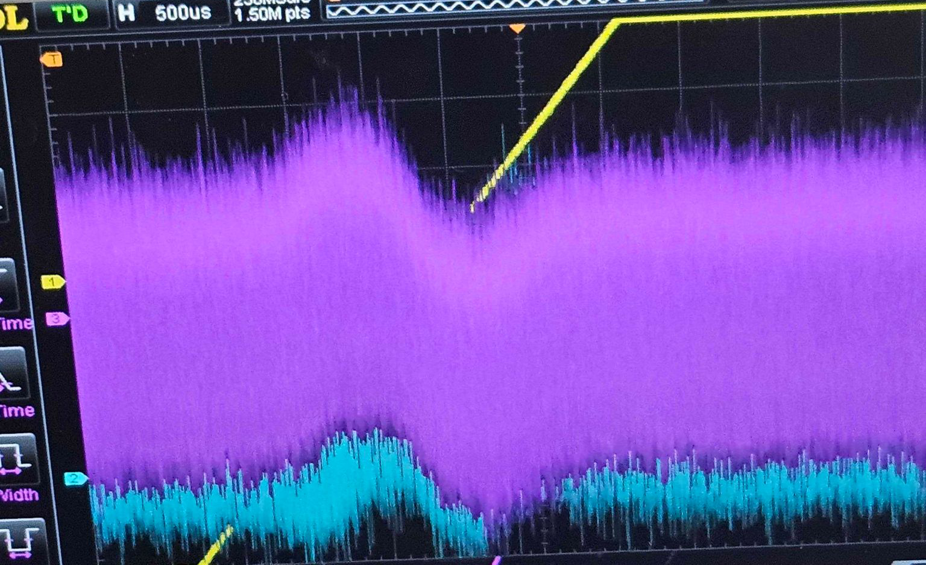
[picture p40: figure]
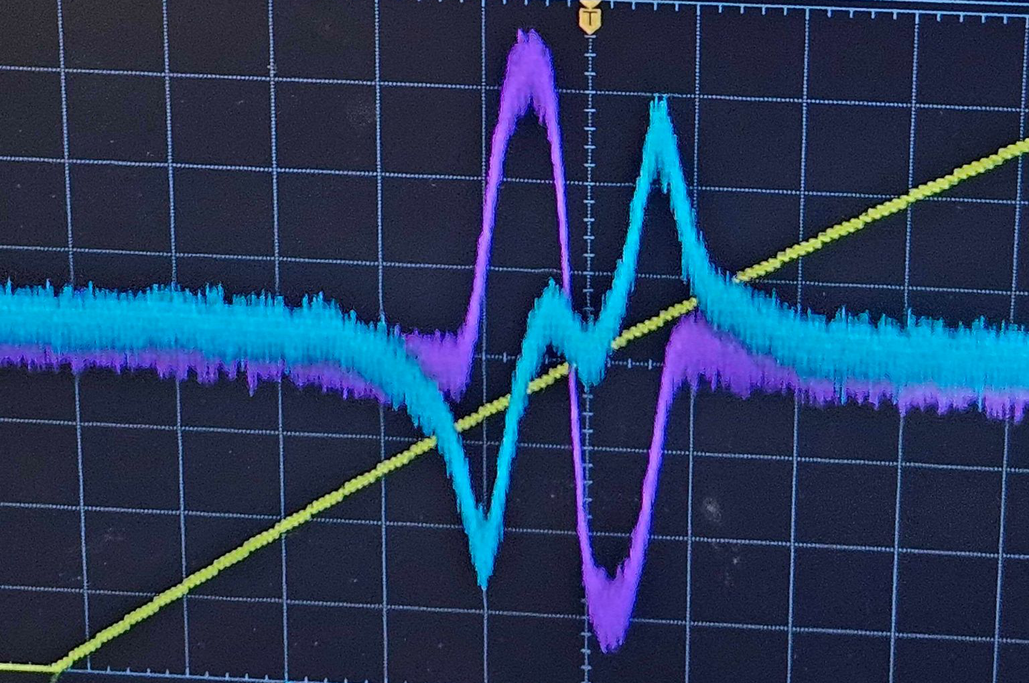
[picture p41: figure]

## How do we Maximize Optical Gain?

Big Idea: The SNR of the error signal we feed to our controller determines the controller’s performance ceiling

## Optimizing Modulation Depth

- Modulation depth (beta) is determined by the voltage ratio of EOM driver amplitude relative to voltage required to induce 180 degree phase shift in EOM
- Determines power distribution over Bessel modes
- Want to concentrate power in 0th and first-order modes

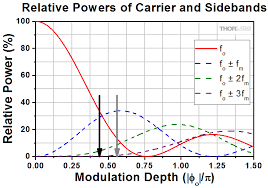
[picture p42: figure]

## Optimizing Demod Phase

- Relative phase between reference signal and input dictates both the sign and magnitude of the demodulated output.
  - Phase difference of over 90 degrees will flip sign
  - Phase difference near 90 degrees will result in very low gain
- We can get around this by demodulating over two axes 90 degrees apart (IQ Demodulation), then ‘align’ the signal.
  - Take both signals and feed to a rotation matrix with calculated adjustment angle set
  - Phase-shift the demod signal directly

## Using a Higher Modulation Frequency

- If the cavity response isn’t very ‘sharp’ (low finesse), then the sidebands might still get attenuated
- To compensate with this, we can modulate/demodulate at a higher frequency
  - For example, keep control circuitry digital but implement the mod/demod over analog

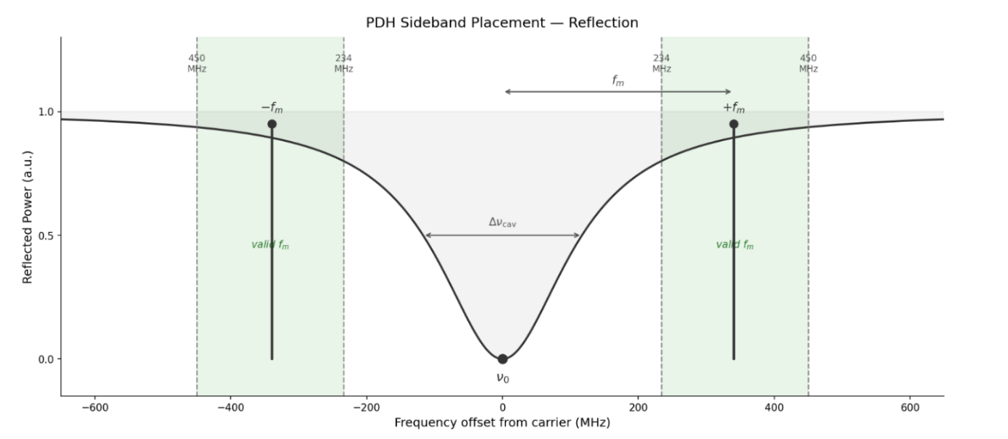
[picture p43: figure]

## Introducing The Controller


## Assessing Controller Performance

- Measure the RMS error signal fed to the controller as input.
- Good controller should reduce this value.
- This should work, right?

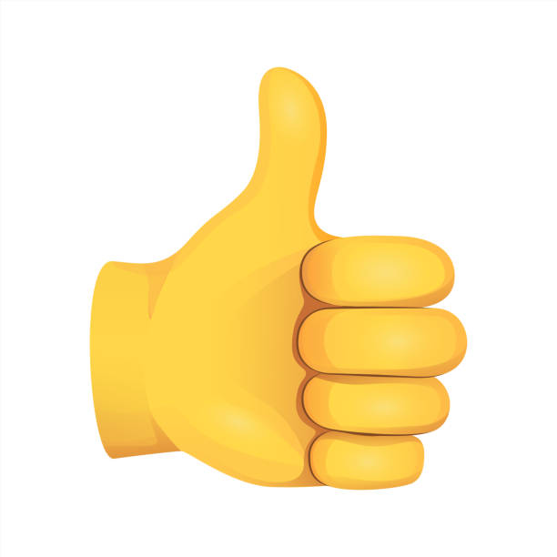
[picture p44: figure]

## No.

## Issue: Optical Error vs Electrical Noise

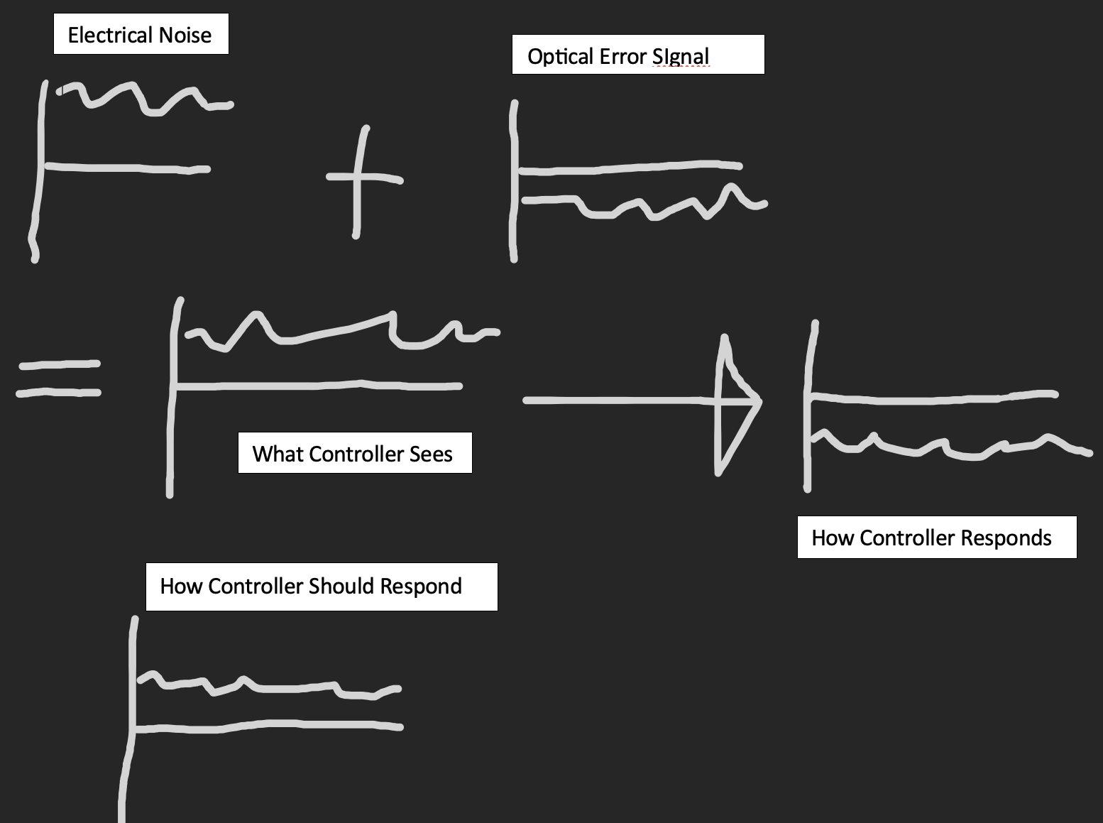
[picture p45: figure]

- The optical signal passes through electrical circuitry before the controller receives it
- This electrical circuitry adds noise that we don’t want our controller to react to
- If we aren’t careful, the controller may also respond to electrical noise

## Solution: Delayed Self-Heterodyne

- Split beam
  - Increase optical frequency on one arm via AOM
  - Delay on the other via fiber delay
- Recombine both signals and get power via Photodiode
- New signal is a sinusoid at AOM modulation frequency, demodulate it then get PSD to approximate laser noise PSD.

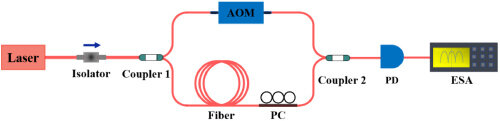
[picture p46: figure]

## Issue: How do we Pick a Delay?

- Delay too long: Will not be able to see phase changes that happen very quickly
- Delay too short: Not enough difference between the two phase values, SNR degrades

## Phase Noise PSD

- Phase difference PSD by itself still not super useful, need to convert to phase noise PSD
- Tau delay is phase shift in freq domain
- Find transfer function relating phase difference noise to phase noise

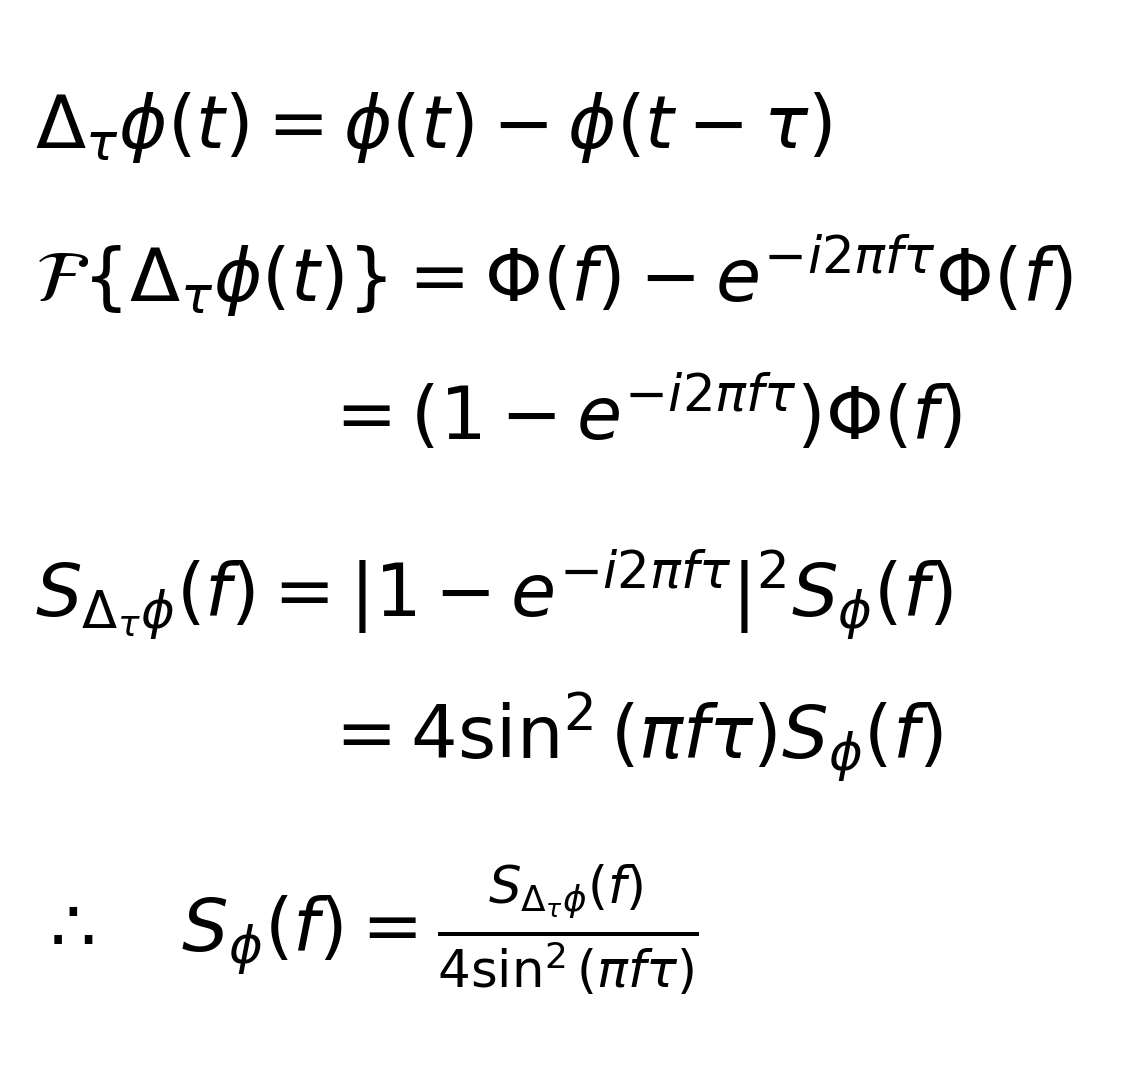
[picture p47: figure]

## Tuning the Controller

Can use band-limited root-mean-square of the phase noise PSD as a metric
1. Get baseline RMS value with controller disengaged
2. Zero Ki, Kd, Kp
3. Increase Kp until we start to see new oscillation spike on phase noise PSD
4. Reduce Kp until spike gone, inc Kd while doing so reduces RMS MZI output PSD
5. Increase Ki while doing so reduces RMS MZI output PSD

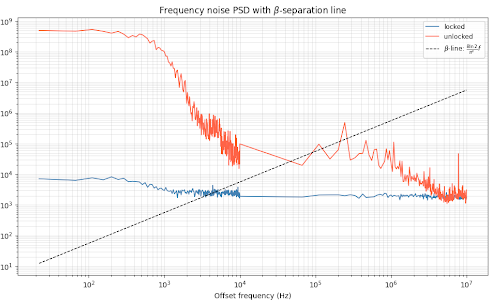
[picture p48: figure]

## Filtering Electrical Noise

- Sometimes electrical noise is just there and there’s nothing we can do about it
- We need to filter it out

## Solution: FIR Filter


## Implementation


- Run control/digital filtering on FPGA fabric
- Mod/demod either on fabric or standalone PCB
- HPS allows the whole system to be software-defined

## HPS Interfacing

- Control plane
  - Lets processor configure FPGA circuitry as needed
  - Latency concern is minimal
- Data plane
  - FPGA can dump its signals into a BRAM block and feed that data to processor’s DMA controller over an AXI3 interface
  - Lets processor get large amounts of real-time data off the FPGA quickly without impeding the fabric’s operation
  - Useful for things like tapping controller/filter signals, viewing PSD’s etc
- GIC interface
  - Fabric can assert interrupt signal to GIC’s IRQ vector
  - Processor can respond to interrupt as needed based on the context

## Issue: Clock Skew and Metastability

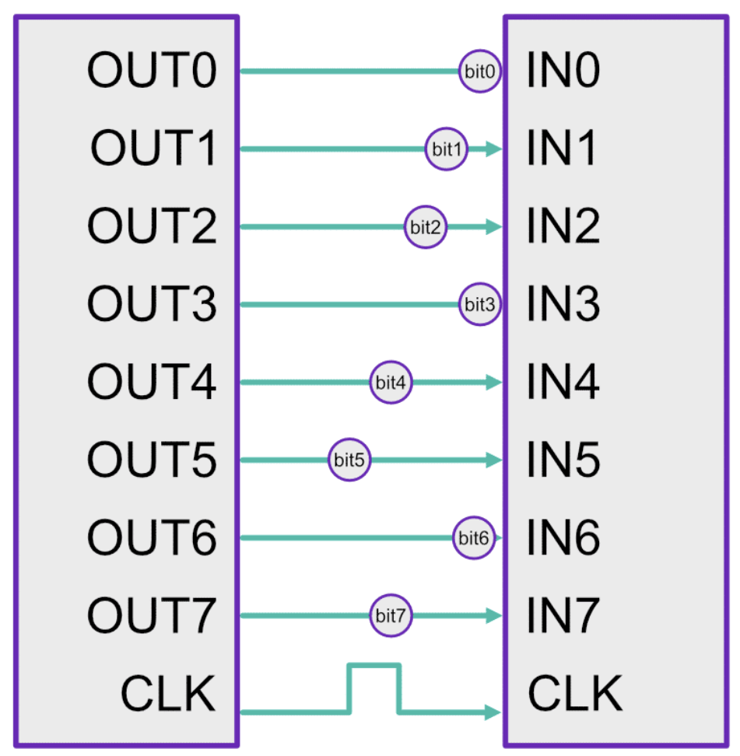
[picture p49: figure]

- Metastability happens when the (changing) signal going into a flip-flop has not been asserted long enough before the clock edge or is not held long enough after the clock edge
- Clock skew happens when the data going into a system doesn’t arrive at the same time as what that system is clocked on
  - Could be metastable
  - Could assume old data is still valid

## Solution Primitive: Flip-Flop Sync

- The flip-flops want to be stable, they just need time :)
- First flip-flop will take brunt of metastable signal, but it has a whole clock cycle to resolve cleanly
- Second flip flop will have exponentially lower chance of also receiving a metastable input
- Need lower probability of metastability? Add more flip flops!

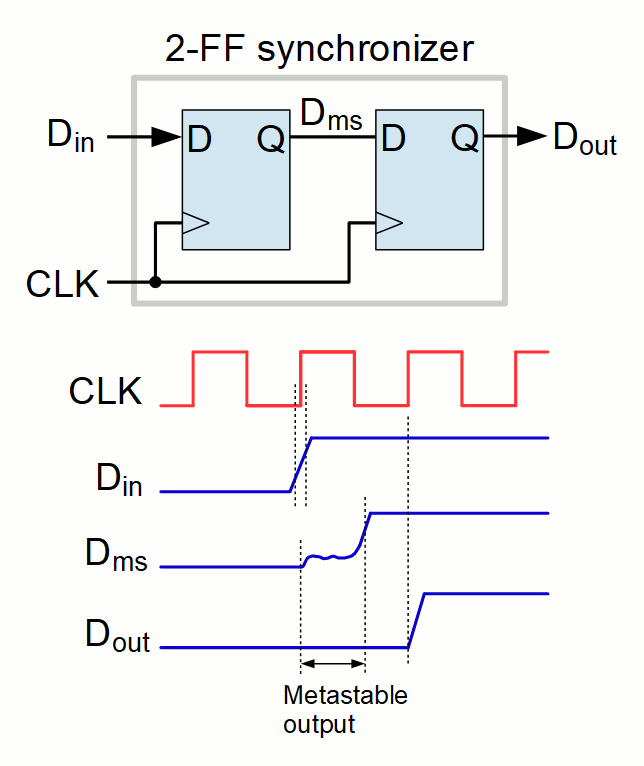
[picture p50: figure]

## Control Plane Solution: Strobe Protocol

- FF-Sync can lower probability of metastable output to ~0
  - Doesn’t guarantee that that output value matched what the input was supposed to be if the input is metastable
- For 1-bit signals this means the signal will get delayed by a clock cycle
- For multi-bit signals, this means that the signal might be torn (like with clock skew)
- Solution: send out our data bits first, then send a strobe bit to mark them as valid
  - If strobe 0-1 transition catches an edge and gets delayed by one cycle, whatever
  - Guarantees that data bits have stabilized
- Can send callback signal to processor when input is received
  - Emit GIC IRQ to notify processor that callback has been sent
  - Processor can service callback either in the IRQ handler directly or use IRQ as a threading signal (UIO handler) etc

## Data Plane Solution: Dual-Port BRAM

- Clock BRAM input on ADC clock domain, clock output on processor domain
- Write to / Write from BRAM via FSM
  - Start-finish protocol on each FSM
  - Start and finish signals 3ff synchronized between fabric core and AXI DMA module feeding to processor’s DMA controller
- Much faster/simpler than async FIFO
  - Easier to debug
  - Can run at max clock rate without overflow, will never jam
  - We have enough BRAM for it… or do we?

## Issue: NCO BRAM Consumption

- Two main ways to generate a sine wave digitally
  - LUT: Have table of sin coefficients and iterate through it
  - CORDIC: Algorithm that calculates coeff with progressively more accuracy, requires multiple clock cycles
- CORDIC will decimate our top-end rate, bad if our cavity finesse is low
  - Need LUT
  - Still want high accuracy at lower freqs and low jitter at high freqs so the table may need to be large
- FULL-size high-resolution LUT can take up a LOT of BRAM
  - ~4096 16-bit coeffs

## Solution: Quarter-Wave Table

- We can just keep a quarter of the sine wave period in memory and flip traversal order/sign as needed as we advance
- Cuts down our memory footprint by a factor of 4!

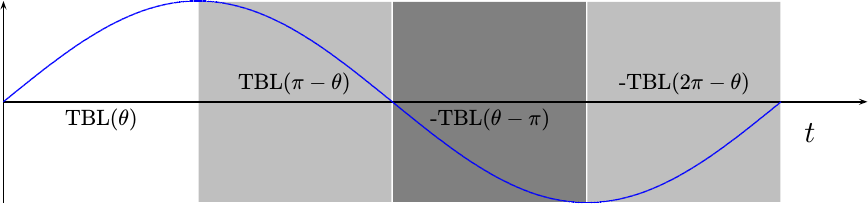
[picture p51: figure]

## What We Covered

1. Why eliminating laser noise is useful
2. Basic principles behind the Pound-Drever-Hall method
3. Practical controller implementation with considerations for the optical environment
4. Hardware-software system integration for better system reconfigurability/ergonomics
5. Implementation considerations

## Questions?

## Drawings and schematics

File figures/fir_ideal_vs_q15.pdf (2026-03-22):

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

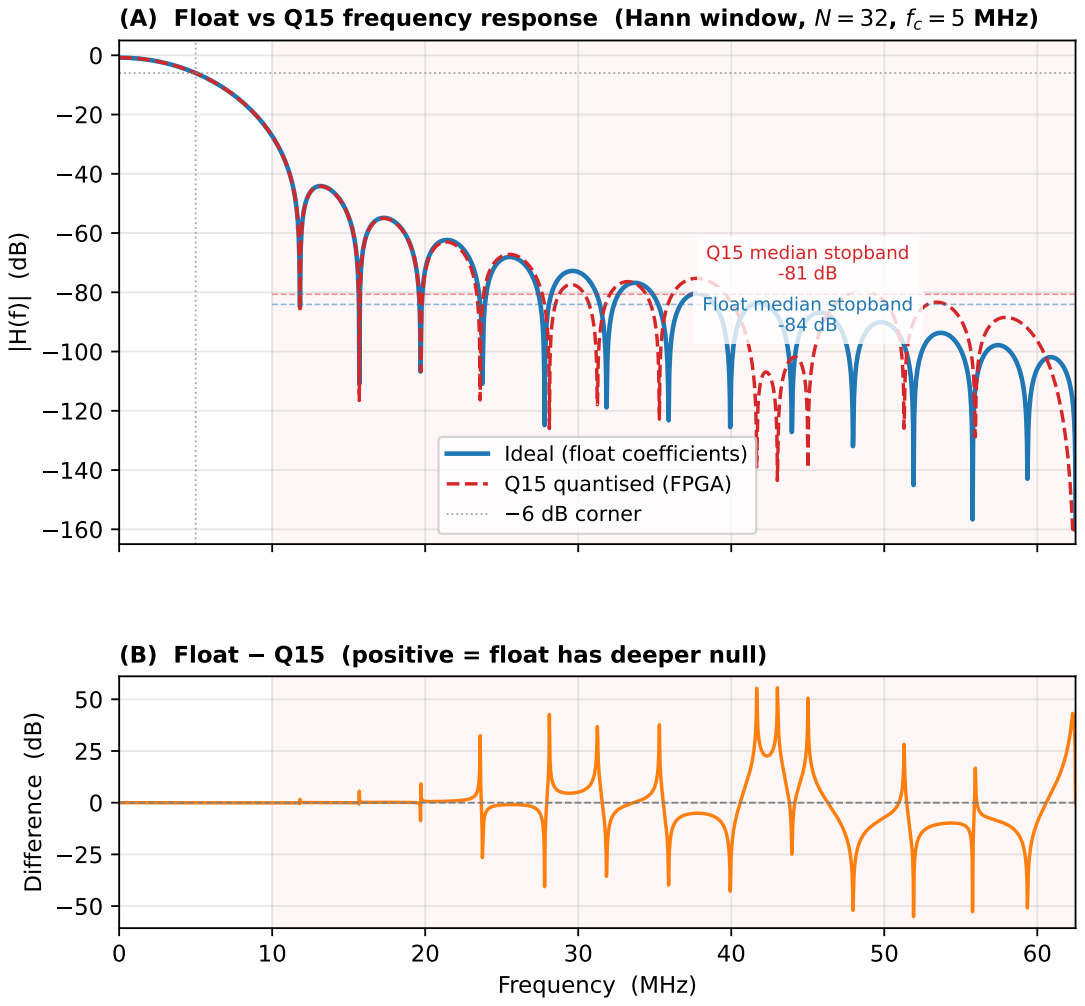
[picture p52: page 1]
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

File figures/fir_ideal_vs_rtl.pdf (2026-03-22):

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

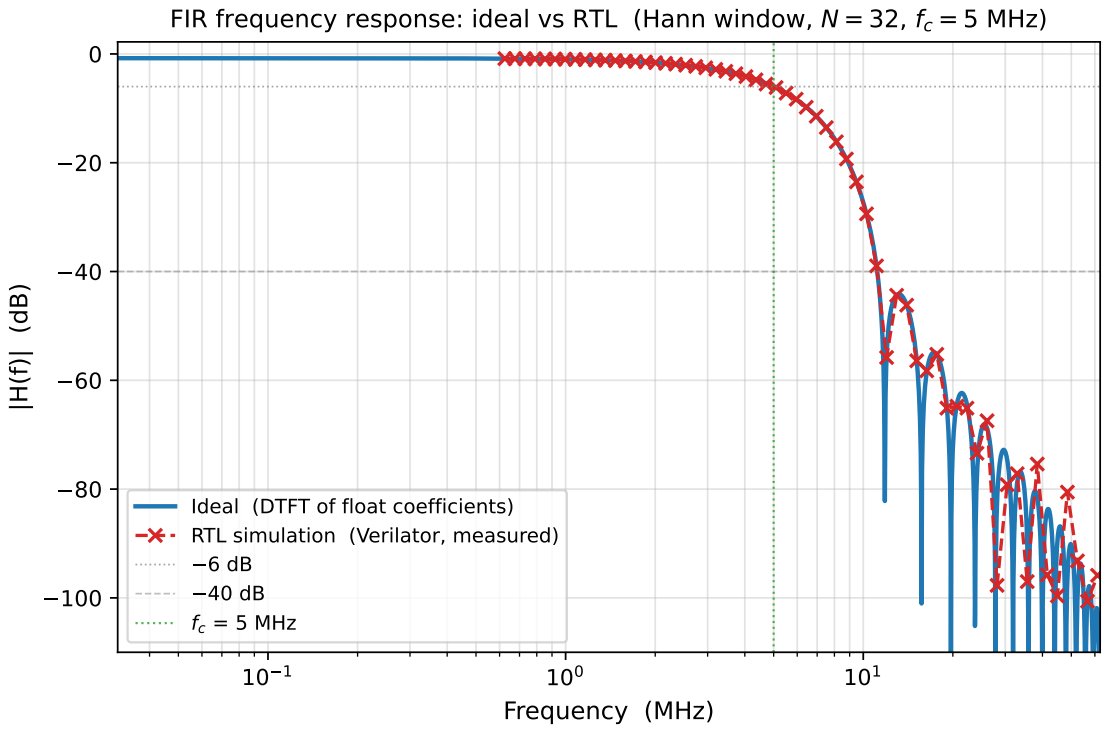
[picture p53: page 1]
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

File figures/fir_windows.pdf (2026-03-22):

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

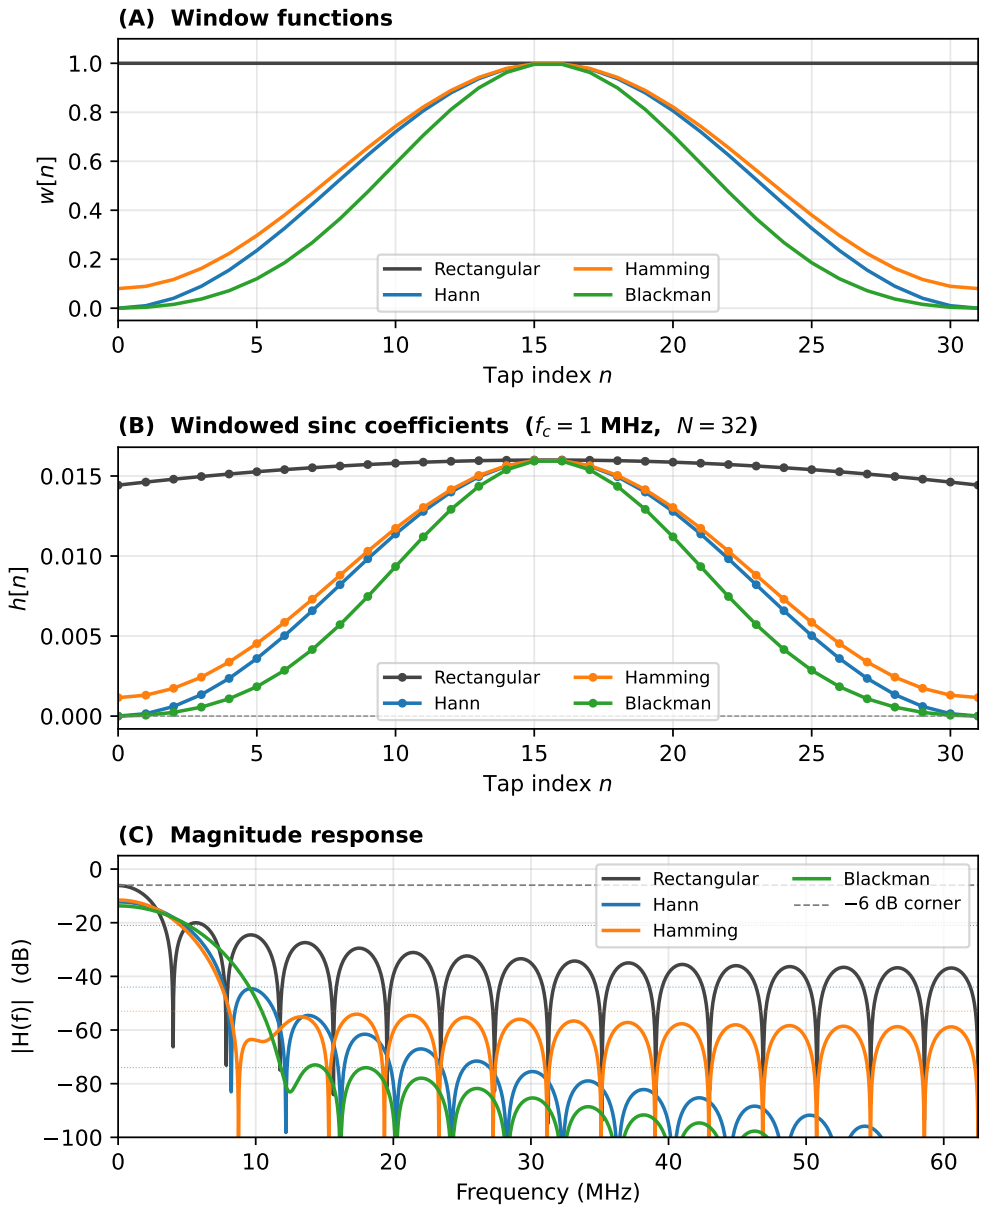
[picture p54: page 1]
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

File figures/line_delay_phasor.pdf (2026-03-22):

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

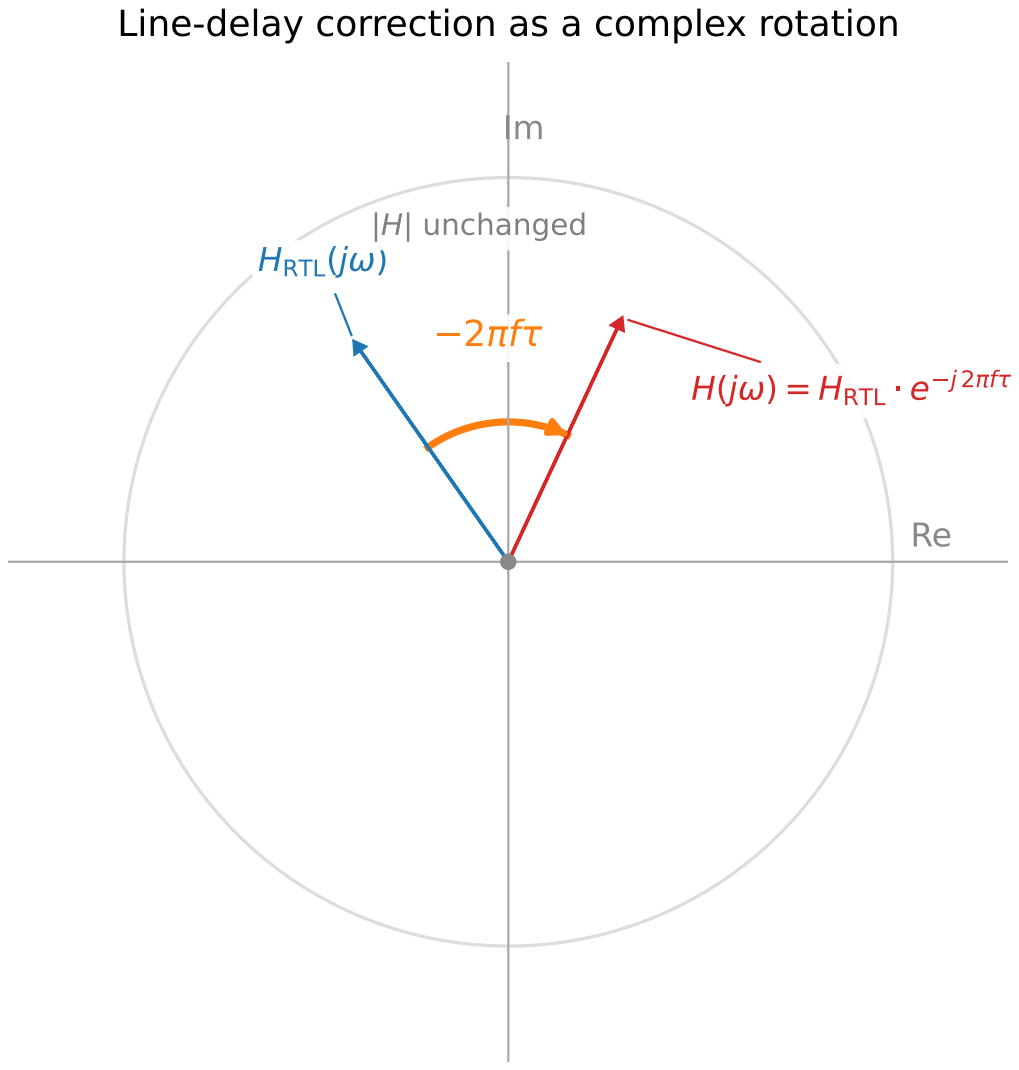
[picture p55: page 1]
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

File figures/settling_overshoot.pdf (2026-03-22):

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

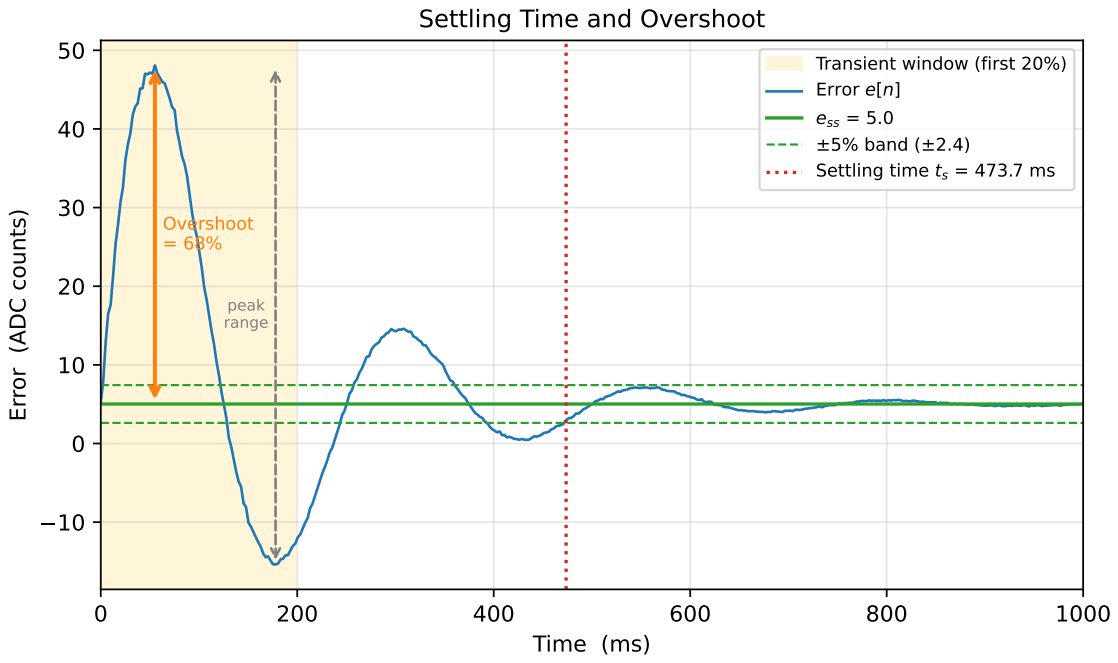
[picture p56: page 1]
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

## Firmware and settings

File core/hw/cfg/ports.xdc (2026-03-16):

# set_property CFGBVS VCCO [current_design]
# set_property CONFIG_VOLTAGE 3.3 [current_design]

### ADC

# data

set_property IOSTANDARD LVCMOS18 [get_ports {adc_dat_a_i[*]}]
set_property IOB TRUE [get_ports {adc_dat_a_i[*]}]

set_property PACKAGE_PIN Y17 [get_ports {adc_dat_a_i[0]}]
set_property PACKAGE_PIN W16 [get_ports {adc_dat_a_i[1]}]
set_property PACKAGE_PIN Y16 [get_ports {adc_dat_a_i[2]}]
set_property PACKAGE_PIN W15 [get_ports {adc_dat_a_i[3]}]
set_property PACKAGE_PIN W14 [get_ports {adc_dat_a_i[4]}]
set_property PACKAGE_PIN Y14 [get_ports {adc_dat_a_i[5]}]
set_property PACKAGE_PIN W13 [get_ports {adc_dat_a_i[6]}]
set_property PACKAGE_PIN V12 [get_ports {adc_dat_a_i[7]}]
set_property PACKAGE_PIN V13 [get_ports {adc_dat_a_i[8]}]
set_property PACKAGE_PIN T14 [get_ports {adc_dat_a_i[9]}]
set_property PACKAGE_PIN T15 [get_ports {adc_dat_a_i[10]}]
set_property PACKAGE_PIN V15 [get_ports {adc_dat_a_i[11]}]
set_property PACKAGE_PIN T16 [get_ports {adc_dat_a_i[12]}]
set_property PACKAGE_PIN V16 [get_ports {adc_dat_a_i[13]}]

set_property IOSTANDARD LVCMOS18 [get_ports {adc_dat_b_i[*]}]
set_property IOB TRUE [get_ports {adc_dat_b_i[*]}]

set_property PACKAGE_PIN R18 [get_ports {adc_dat_b_i[0]}]
set_property PACKAGE_PIN P16 [get_ports {adc_dat_b_i[1]}]
set_property PACKAGE_PIN P18 [get_ports {adc_dat_b_i[2]}]
set_property PACKAGE_PIN N17 [get_ports {adc_dat_b_i[3]}]
set_property PACKAGE_PIN R19 [get_ports {adc_dat_b_i[4]}]
set_property PACKAGE_PIN T20 [get_ports {adc_dat_b_i[5]}]
set_property PACKAGE_PIN T19 [get_ports {adc_dat_b_i[6]}]
set_property PACKAGE_PIN U20 [get_ports {adc_dat_b_i[7]}]
set_property PACKAGE_PIN V20 [get_ports {adc_dat_b_i[8]}]
set_property PACKAGE_PIN W20 [get_ports {adc_dat_b_i[9]}]
set_property PACKAGE_PIN W19 [get_ports {adc_dat_b_i[10]}]
set_property PACKAGE_PIN Y19 [get_ports {adc_dat_b_i[11]}]
set_property PACKAGE_PIN W18 [get_ports {adc_dat_b_i[12]}]
set_property PACKAGE_PIN Y18 [get_ports {adc_dat_b_i[13]}]

# clock input

set_property IOSTANDARD DIFF_HSTL_I_18 [get_ports adc_clk_p_i]
set_property IOSTANDARD DIFF_HSTL_I_18 [get_ports adc_clk_n_i]
set_property PACKAGE_PIN U18 [get_ports adc_clk_p_i]
set_property PACKAGE_PIN U19 [get_ports adc_clk_n_i]

# clock output

set_property IOSTANDARD LVCMOS18 [get_ports adc_enc_p_o]
set_property IOSTANDARD LVCMOS18 [get_ports adc_enc_n_o]

set_property SLEW FAST [get_ports adc_enc_p_o]
set_property SLEW FAST [get_ports adc_enc_n_o]

set_property DRIVE 8 [get_ports adc_enc_p_o]
set_property DRIVE 8 [get_ports adc_enc_n_o]

set_property PACKAGE_PIN N20 [get_ports adc_enc_p_o]
set_property PACKAGE_PIN P20 [get_ports adc_enc_n_o]

# clock duty cycle stabilizer (CSn)

set_property IOSTANDARD LVCMOS18 [get_ports adc_csn_o]
set_property PACKAGE_PIN V18 [get_ports adc_csn_o]
set_property SLEW FAST [get_ports adc_csn_o]
set_property DRIVE 8 [get_ports adc_csn_o]

### DAC

# data

set_property IOSTANDARD LVCMOS33 [get_ports {dac_dat_o[*]}]
set_property SLEW FAST [get_ports {dac_dat_o[*]}]
set_property DRIVE 8 [get_ports {dac_dat_o[*]}]
# set_property IOB TRUE [get_ports {dac_dat_o[*]}]

set_property PACKAGE_PIN M19 [get_ports {dac_dat_o[0]}]
set_property PACKAGE_PIN M20 [get_ports {dac_dat_o[1]}]
set_property PACKAGE_PIN L19 [get_ports {dac_dat_o[2]}]
set_property PACKAGE_PIN L20 [get_ports {dac_dat_o[3]}]
set_property PACKAGE_PIN K19 [get_ports {dac_dat_o[4]}]
set_property PACKAGE_PIN J19 [get_ports {dac_dat_o[5]}]
set_property PACKAGE_PIN J20 [get_ports {dac_dat_o[6]}]
set_property PACKAGE_PIN H20 [get_ports {dac_dat_o[7]}]
set_property PACKAGE_PIN G19 [get_ports {dac_dat_o[8]}]
set_property PACKAGE_PIN G20 [get_ports {dac_dat_o[9]}]
set_property PACKAGE_PIN F19 [get_ports {dac_dat_o[10]}]
set_property PACKAGE_PIN F20 [get_ports {dac_dat_o[11]}]
set_property PACKAGE_PIN D20 [get_ports {dac_dat_o[12]}]
set_property PACKAGE_PIN D19 [get_ports {dac_dat_o[13]}]

# control

set_property IOSTANDARD LVCMOS33 [get_ports dac_clk_o]
set_property IOSTANDARD LVCMOS33 [get_ports dac_rst_o]
set_property IOSTANDARD LVCMOS33 [get_ports dac_sel_o]
set_property IOSTANDARD LVCMOS33 [get_ports dac_wrt_o]
set_property SLEW FAST [get_ports dac_*_o]
set_property DRIVE 8 [get_ports dac_clk_o]
set_property DRIVE 8 [get_ports dac_rst_o]
set_property DRIVE 8 [get_ports dac_sel_o]
set_property DRIVE 8 [get_ports dac_wrt_o]
# set_property IOB TRUE [get_ports {dac_*_o}]

set_property PACKAGE_PIN M17 [get_ports dac_wrt_o]
set_property PACKAGE_PIN N16 [get_ports dac_sel_o]
set_property PACKAGE_PIN M18 [get_ports dac_clk_o]
set_property PACKAGE_PIN N15 [get_ports dac_rst_o]

### PWM

set_property IOSTANDARD LVCMOS18 [get_ports {dac_pwm_o[*]}]
set_property SLEW FAST [get_ports {dac_pwm_o[*]}]
set_property DRIVE 12 [get_ports {dac_pwm_o[*]}]
# set_property IOB TRUE [get_ports {dac_pwm_o[*]}]
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

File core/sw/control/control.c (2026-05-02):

#include <math.h>
#include <stdint.h>
#include <unistd.h>
#include <string.h>
#include <sys/select.h>
#include "server.h"
#include "hw_common.h"
#include "control.h"

#define RESET_ON 1
#define RESET_OFF 0
#define LOCK_POINT_FLAG "lock_point"
#define DERIVED_SLOPE_FLAG "derived_slope"
#define RETURN_CODE "RETURN_CODE"
#define CMD "CMD_CB"

static inline pdh_callback_t pdh_execute_cmd(pdh_cmd_t cmd)
{
    cmd.strobe.val = 0;
    pdh_send_cmd(cmd);
    cmd.strobe.val = 1;
    pdh_send_cmd(cmd);

    pdh_callback_t cb = { 0 };
    pdh_get_callback(&cb);
    return cb;
}

/* Send strobe without reading callback */
void pdh_strobe_cmd(pdh_cmd_t cmd)
{
    cmd.strobe.val = 0;
    pdh_send_cmd(cmd);
    cmd.strobe.val = 1;
    pdh_send_cmd(cmd);
}

static inline int push_ctx_cb(cmd_ctx_t* ctx, size_t* index, void* value, int tag, const char* name) //Value should always be an echo
{
    switch(tag)
    {
        case FLOAT_TAG:
            ctx->output.output_items[*index].data.f = *(float*)value;
            ctx->output.output_items[*index].tag = FLOAT_TAG;
            strcpy(ctx->output.output_items[*index].name, name);
            break;

        case INT_TAG:
            ctx->output.output_items[*index].data.i = *(int32_t*)value;
            ctx->output.output_items[*index].tag = INT_TAG;
            strcpy(ctx->output.output_items[*index].name, name);
            break;

        case INT16_TAG:
            ctx->output.output_items[*index].data.i = *(int16_t*)value;
            ctx->output.output_items[*index].tag = INT_TAG;
            strcpy(ctx->output.output_items[*index].name, name);
            break;

        case UINT_TAG:
            ctx->output.output_items[*index].data.u = *(uint32_t*)value;
            ctx->output.output_items[*index].tag = UINT_TAG;
            strcpy(ctx->output.output_items[*index].name, name);
            break;

        default:
            DEBUG_INFO("INVALID TAG CODE: %d", tag); 
            return 1;
    }

    ctx->output.num_outputs = ++*index;
    return 0;
}


static inline int validate_cb(void* cb, void* expected, int tag, const char* func, const char* name, int success_code, int fail_code)
{
    int return_code = success_code;

    switch(tag)
    {
        case FLOAT_TAG:
            if(*(float*)cb != *(float*)expected) 
            {
                DEBUG_INFO("%s::ERROR: Expected %f for %s but got %f", func, *(float*)expected, name, *(float*)cb);
                return_code = fail_code;
            }
            break;

        case INT_TAG:
            if(*(int32_t*)cb != *(int32_t*)expected) 
            {
                DEBUG_INFO("%s::ERROR: Expected %d for %s but got %d", func,*(int32_t*)expected, name, *(int32_t*)cb);
                return_code = fail_code;
            }
            break;

        case INT16_TAG:
            if(*(int16_t*)cb != *(int16_t*)expected) 
            {
                DEBUG_INFO("%s::ERROR: Expected %d for %s but got %d", func,*(int16_t*)expected, name, *(int16_t*)cb);
                return_code = fail_code;
            }
            break;

        case UINT_TAG:
            if(*(uint32_t*)cb != *(uint32_t*)expected) 
            {
                DEBUG_INFO("%s::ERROR: Expected %u for %s but got %u", func, *(uint32_t*)expected, name, *(uint32_t*)cb);
                return_code = fail_code;
            }
            break;

        default:
            DEBUG_INFO("INVALID TAG CODE: %d", tag); 
            return -1;
    }

    return return_code;
}


int cmd_reset_fpga(cmd_ctx_t* ctx) //TODO: Better rst cb verification
{
    int return_code = PDH_OK;

    pdh_cmd_t cmd;
    cmd.raw = 0;

    cmd.rst_cmd.rst = RESET_ON;
    pdh_send_cmd(cmd); 
    cmd.rst_cmd.rst = RESET_OFF;
    pdh_send_cmd(cmd);

    pdh_callback_t callback;
    callback.raw = 0;
    pdh_get_callback(&callback);


    uint32_t rst_raw  = callback.raw;

    size_t index = 0;
    push_ctx_cb(ctx, &index, &rst_raw, UINT_TAG, "RST_RAW_CB");

    return return_code;
}


int cmd_set_led(cmd_ctx_t* ctx)
{
    
    pdh_cmd_t cmd;
    cmd.raw = 0;

    int return_code = SET_LED_OK;
    uint32_t led_code = ctx->uint_args[0];
    
    size_t index = 0;

    if (led_code > 255)
    {
        DEBUG_INFO("ERROR EXECUTING: %s! --- Invalid LED_CODE: %d\n", __func__, led_code);
        return_code = SET_LED_INVALID_LED;
    }

    else
    {
        cmd.led_cmd.cmd = CMD_SET_LED;
        cmd.led_cmd.led_code = led_code;
        pdh_callback_t callback = pdh_execute_cmd(cmd);


        uint32_t echo_code = callback.led_cb.func_callback;
        uint32_t echo_cmd = callback.led_cb.cmd;
        push_ctx_cb(ctx, &index, &echo_code, UINT_TAG, "LED_CODE_CB");
        push_ctx_cb(ctx, &index, &echo_cmd, UINT_TAG, CMD);
        
        return_code = validate_cb(&echo_code, &led_code, UINT_TAG, __func__, "LED_CODE", return_code, SET_LED_INVALID_LED_CB);
        uint32_t cmdval = cmd.cmd.val;
        return_code = validate_cb(&echo_cmd, &cmdval, UINT_TAG, __func__, CMD, return_code, PDH_INVALID_CMD);
    }
    
    return return_code;
}


int cmd_get_adc(cmd_ctx_t *ctx)
{
    int return_code = GET_ADC_OK;

    pdh_cmd_t cmd;
    cmd.raw = 0;
    cmd.adc_cmd.cmd = CMD_GET_ADC;
    pdh_callback_t callback = pdh_execute_cmd(cmd); 
    
    uint32_t echo_adc0_code = callback.adc_cb.adc_0_code; //TODO: Range checking
    uint32_t echo_adc1_code = callback.adc_cb.adc_1_code;
    float adc0_converted = -1.0f * (echo_adc0_code * (2.0f/16383.0f) - 1.0f);
    float adc1_converted = -1.0f * (echo_adc1_code * (2.0f/16383.0f) - 1.0f);
    uint32_t echo_cmd = callback.adc_cb.cmd;

    size_t index = 0;
    push_ctx_cb(ctx, &index, &echo_adc0_code, UINT_TAG, "IN1");
    push_ctx_cb(ctx, &index, &echo_adc1_code, UINT_TAG, "IN2");
    push_ctx_cb(ctx, &index, &adc0_converted, FLOAT_TAG, "IN1_V");
    push_ctx_cb(ctx, &index, &adc1_converted, FLOAT_TAG, "IN2_V");
    push_ctx_cb(ctx, &index, &echo_cmd, UINT_TAG, CMD);
    
    uint32_t cmdval = cmd.cmd.val;
    return_code = validate_cb(&echo_cmd, &cmdval, UINT_TAG, __func__, CMD, return_code, PDH_INVALID_CMD);
    return return_code;
}
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

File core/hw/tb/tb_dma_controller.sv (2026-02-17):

`timescale 1ns/1ps

// ------------------------------------------------------------
// Minimal edge detector used by your DUT
// ------------------------------------------------------------
//module posedge_detector (
//    input  logic clk,
//    input  logic rst,
//    input  logic D,
//    output logic Q
//);
//    logic D_d;
//    always_ff @(posedge clk or posedge rst) begin
//        if (rst) begin
//            D_d <= 1'b0;
//            Q   <= 1'b0;
//        end else begin
//            Q   <= (D && !D_d);
//            D_d <= D;
//        end
//    end
//endmodule


// ------------------------------------------------------------
// TB
// ------------------------------------------------------------
module tb_dma_controller;

    // -----------------------------
    // Clock/reset
    // -----------------------------
    logic aclk;
    logic rst_i;

    initial begin
        aclk = 1'b0;
        forever #5 aclk = ~aclk; // 100MHz
    end

    // -----------------------------
    // DUT I/O
    // -----------------------------
    logic [31:0] m_axi_awaddr;
    logic        m_axi_awvalid;
    logic        m_axi_awready;
    logic [3:0]  m_axi_awlen;
    logic [2:0]  m_axi_awsize;
    logic [1:0]  m_axi_awburst;

    logic [63:0] m_axi_wdata;
    logic        m_axi_wvalid;
    logic        m_axi_wready;
    logic        m_axi_bvalid;
    logic        m_axi_bready;
    logic [1:0]  m_axi_bresp;
    logic [7:0]  m_axi_wstrb;
    logic        m_axi_wlast;

    logic        enable_i;
    logic [63:0] data_i;
    logic        finished_o;
    logic        engaged_o;

    // -----------------------------
    // Instantiate DUT
    // -----------------------------
    dma_controller 
    #(
        .DMA_SIZE(32'h000000A0)
    ) dut
    (
        .aclk(aclk),
        .rst_i(rst_i),

        .m_axi_awaddr(m_axi_awaddr),
        .m_axi_awvalid(m_axi_awvalid),
        .m_axi_awready(m_axi_awready),
        .m_axi_awlen(m_axi_awlen),
        .m_axi_awsize(m_axi_awsize),
        .m_axi_awburst(m_axi_awburst),

        .m_axi_wdata(m_axi_wdata),
        .m_axi_wvalid(m_axi_wvalid),
        .m_axi_wready(m_axi_wready),
        .m_axi_bvalid(m_axi_bvalid),
        .m_axi_bready(m_axi_bready),
        .m_axi_bresp(m_axi_bresp),
        .m_axi_wstrb(m_axi_wstrb),
        .m_axi_wlast(m_axi_wlast),

        .enable_i(enable_i),
        .data_i(data_i),
        .dma_ready_o(finished_o)
    );

    // -----------------------------
    // Wave dump ALWAYS ON
    // -----------------------------
    initial begin
        $dumpfile("dumps/dma_tb.vcd");
        $dumpvars(0, tb_dma_controller);
    end

    // -----------------------------
    // Data source: incrementing pattern
    // -----------------------------
    always_ff @(posedge aclk or posedge rst_i) begin
        if (rst_i) data_i <= 64'd0;
        else       data_i <= data_i + 64'd1;
    end

    // -----------------------------
    // Simple AXI sink model knobs
    // -----------------------------
    typedef enum int {MODE_TEST1 = 1, MODE_TEST2 = 2} tb_mode_t;
    tb_mode_t mode;

    int aw_stall_countdown;
    int b_delay_countdown;
    bit b_pending;

    // "Stall pattern" counters
    int cyc;
    always_ff @(posedge aclk or posedge rst_i) begin
        if (rst_i) cyc <= 0;
        else       cyc <= cyc + 1;
    end

    // Dumb sink behavior
    always_ff @(posedge aclk or posedge rst_i) begin
        if (rst_i) begin
            m_axi_awready <= 1'b1;
            m_axi_wready  <= 1'b1;
            m_axi_bvalid  <= 1'b0;
            m_axi_bresp   <= 2'b00; // OKAY
            b_pending     <= 1'b0;
            aw_stall_countdown <= 0;
            b_delay_countdown  <= 0;
        end else begin
            // defaults each cycle
            m_axi_bvalid <= 1'b0;

            // TEST1: no stalls, BVALID one cycle after last beat
            if (mode == MODE_TEST1) begin
                m_axi_awready <= 1'b1;
                m_axi_wready  <= 1'b1;

                if (m_axi_wvalid && m_axi_wready && m_axi_wlast)
                    b_pending <= 1'b1;

                if (b_pending) begin
                    m_axi_bvalid <= 1'b1;
                    b_pending    <= 1'b0;
                end
            end

            // TEST2: stalls + delayed B response
            if (mode == MODE_TEST2) begin
                // AWREADY: stall for a few cycles right after enable pulse hits
                if (aw_stall_countdown > 0) begin
                    m_axi_awready <= 1'b0;
                    aw_stall_countdown <= aw_stall_countdown - 1;
                end else begin
                    m_axi_awready <= 1'b1;
                end

                // WREADY: simple periodic stall (low every 4th cycle)
                // (keeps it deterministic)
                if ((cyc % 4) == 0) m_axi_wready <= 1'b0;
                else                m_axi_wready <= 1'b1;

                // When last beat is accepted, schedule BVALID after delay
                if (m_axi_wvalid && m_axi_wready && m_axi_wlast) begin
                    b_pending <= 1'b1;
                    b_delay_countdown <= 3; // delay 3 cycles
                end

                if (b_pending) begin
                    if (b_delay_countdown > 0) begin
                        b_delay_countdown <= b_delay_countdown - 1;
                    end else begin
                        m_axi_bvalid <= 1'b1;
                        b_pending    <= 1'b0;
                    end
                end
            end
        end
    end

    // -----------------------------
    // Scoreboard / checks
    // -----------------------------
    int  err;
    int  beats_seen;
    bit  saw_aw;
    bit  saw_b;
    logic [31:0] awaddr_first;
    logic [31:0] awaddr_second;

    // For stall stability check (Test2)
    logic [63:0] wdata_hold;
    bit          holding;

    task automatic reset_scoreboard();
        begin
            err         = 0;
            beats_seen  = 0;
            saw_aw      = 0;
            saw_b       = 0;
            awaddr_first  = 32'h0;
            awaddr_second = 32'h0;
            holding     = 0;
            wdata_hold  = 64'h0;
        end
    endtask

    // Monitor transactions
    always_ff @(posedge aclk or posedge rst_i) begin
        if (rst_i) begin
            reset_scoreboard();
        end else begin
            // AW handshake
            if (m_axi_awvalid && m_axi_awready) begin
                if (!saw_aw) begin
                    saw_aw <= 1;
                    awaddr_first <= m_axi_awaddr;
                end else if (awaddr_second == 32'h0) begin
                    // capture second awaddr for increment check if it happens
                    awaddr_second <= m_axi_awaddr;
                end
            end
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

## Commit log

2025-10-31 Dc power sweep
2025-10-31 pd power
2025-11-21 update lab and build system
    [80mA_1V_sin_1kHz_no_eom_pitaya.csv, 80mA_1V_sin_800Hz_eom_16MHz.csv, 80mA_1V_sin_800Hz_eom_1MHz_pitaya.csv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]
2025-11-22 add lock-in skeleton
    [80mA_1V_sin_1kHz_no_eom_pitaya.csv, 80mA_1V_sin_800Hz_eom_16MHz.csv, 80mA_1V_sin_800Hz_eom_1MHz_pitaya.csv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]
2025-11-22 rework for linux env
    [lock_in.h]
2025-11-26 first test results
    [lockin_log.csv]
2025-11-26 bug fix
    [lockin_log.csv]
2025-11-26 better logging
    [lockin_log.csv]
2025-11-26 better log, need to find a better way to get data off rp
    [lockin_log.csv]
2025-11-26 new data
    [lockin_log2.csv]
2025-11-26 this is very tedious
    [lockin_log3.csv]
2025-11-26 ill squash these later dw
    [lockin_log3.csv]
2025-11-27 add basic test client
    [lockin_log2.csv]
2025-11-30 allow sweeps in reverse and normalize further
    [lock_in.h]
2025-11-30 PD CAD file
    [Spacer_16.75mm.sldprt, Spacer_6.5mm.sldprt]
2025-11-30 PD PCB STL files
    [Spacer_16.75mm.STL, Spacer_16.75mm.sldprt, Spacer_6.5mm.STL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]
2026-01-05 added ac power estimate
2026-01-06 led controller passing tests
2026-01-09 Added simulation files for tia/afe, restructured pcb folder, updated gitignore file (#5)
    [Spacer_16.75mm.STL, Spacer_16.75mm.sldprt, Spacer_6.5mm.STL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]
2026-01-09 Added new bandpass topology, and added scratchpad filter testing schematic (#6)
2026-01-09 pending physical board test
2026-01-10 better 67 test and fix synth bug
    [pdh_core.sv, ports.xdc]
2026-01-10 wire in DAC
2026-01-15 adc working
2026-01-17 non-inverted adc internal representation
    [pdh_core.sv]
2026-01-21 pending inital dma test on board
2026-01-21 dma writing into memory, pending data integrity check
2026-01-22 dma got hands
2026-01-26 TODO: Get rid of these insidious vivado implicit wiring assumptions
2026-01-31 negedge dac clocking as per AD9763 datasheet fixes observed DAC lag when switching from high mag neg to high mag pos voltage
    [pdh_core.sv]
2026-02-04 pid cp
2026-02-05 basic PID logic working
2026-02-09 pid controller integration into pdh core, expand cs cb range, dma decimation bug fix, better dac_wrt handling more conducive to PID operation, refactor cb structs
    [control.c, hw_common.h, pdh_core.sv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]
2026-02-15 pid working
2026-02-17 fix rotation glitch and bram fsm enable timing
    [pdh_core.sv, ports.xdc, test.py]
2026-02-17 better dma logic
2026-02-18 better PID coefficient setting
2026-02-26 new lockin and delete old lab stuff
    [85mA_1V_sin_800Hz_eom_nomod_100xattenuation.csv, lockin_log.csv, lockin_log3.csv]
2026-02-27 Add files via upload
    SolidWorks files uploaded to GitHub.
    [Spacer_20mm.STL, Spacer_20mm.sldprt, Spacer_22mm.SLDPRT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]
2026-03-03 but I like this one
    [nco_out.csv]
2026-03-05 FIR working on board
    [fir_coeffs_example.csv]
2026-03-05 FIR freq response sim working
    [fir_coeffs_example.csv]
2026-03-07 gain adjustment for PID controller
2026-03-08 ladies and gentlemen, we got him
    [post_pdh.csv, pre_pdh.csv]
2026-03-09 add option for controller bias and psd raw dma export for further processing
2026-03-09 psd cake tracker
    [post_pdh.csv, pre_pdh.csv]
2026-03-13 egain added
    [circulator_sweep.csv, fiber_aligned_with_splitter.csv, test_sweep1.csv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]
2026-03-15 better controller correction quality metrics
    [circulator_sweep.csv, fiber_aligned_with_splitter.csv]
2026-03-15 interrupt-based callback working
2026-03-16 add mounting script
2026-03-16 say hi to on-board iq demod
2026-05-02 gui bug fix and stop persistent sweep from contaminating dma captures
    [control.c]
